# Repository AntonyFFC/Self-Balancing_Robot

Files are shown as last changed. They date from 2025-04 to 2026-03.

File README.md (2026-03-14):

# Self-Balancing Robot

A two-wheel self-balancing robot project combining embedded systems firmware, control theory, a cross-platform mobile app, and data-visualisation tools.

---

## Table of Contents

- [Overview](#overview)
- [Hardware](#hardware)
- [Repository Structure](#repository-structure)
- [Firmware Variants](#firmware-variants)
  - [ESP32 - Arduino IDE (primary)](#esp32---arduino-ide-primary)
  - [ESP32 - ESP-IDF](#esp32---esp-idf)
  - [STM32](#stm32)
  - [Arduino IDE (original)](#arduino-ide-original)
- [Control Algorithm](#control-algorithm)
- [Mobile App](#mobile-app)
- [Visualisation Tools](#visualisation-tools)
- [Simulations](#simulations)
- [CAD Models](#cad-models)
- [Getting Started](#getting-started)
- [License](#license)

---

## Overview

The robot maintains vertical balance on two wheels using a real-time PID control loop running at 100 Hz. An MPU6050 IMU provides pitch-angle feedback via its built-in DMP. The controller outputs PWM signals to an L298N dual H-bridge motor driver. The primary firmware runs on an **ESP32** microcontroller and uses built-in WiFi for real-time telemetry and remote PID tuning.

---

## Hardware

| Component | Details |
|---|---|
| **Microcontroller** | ESP32 dual-core (primary) · STM32F103 (alternative) |
| **IMU** | MPU6050 – 6-axis accelerometer & gyroscope (I²C, DMP firmware) |
| **Motor Driver** | L298N dual-channel H-bridge |
| **Wireless** | Built-in WiFi (ESP32) · nRF24L01+ 2.4 GHz RF module (STM32) |
| **Motors** | DC geared motors with PWM speed control |

### Chassis

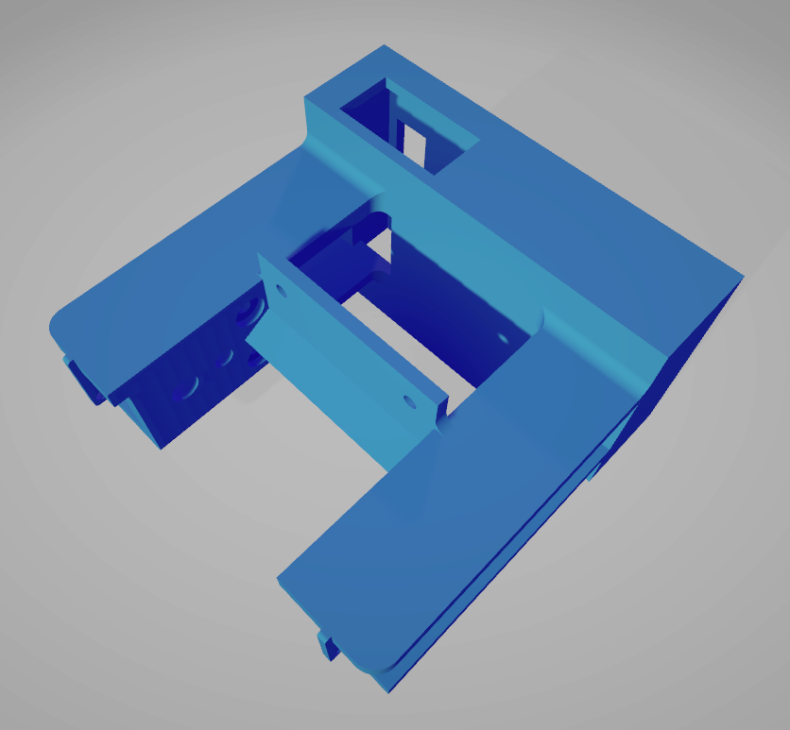
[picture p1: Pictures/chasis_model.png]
Chassis model


---

## Repository Structure

```
SelfBalancing-Robot/
├── esp32_s-b_r_fromArIDE/         # ESP32 firmware - Arduino IDE style (primary)
├── esp32_s-b_r/                   # ESP32 firmware - ESP-IDF / CMake
├── stm32_s-b_r/                   # STM32F1 firmware (CubeIDE)
├── stm32_s-b_r_t/                 # STM32F1 alternative / test build
├── self-balancing-robot_arduinoIDE/# Original Arduino IDE version
├── robot_control_app/             # Flutter cross-platform mobile app
├── Python_Plotting/               # Real-time UDP data visualisation
├── csv_py_plot/                   # CSV playback plotting
├── simulations/                   # MATLAB/Simulink models & analysis
├── CAD/                           # FreeCAD & STL 3D models
├── Pictures/                      # Project images
├── diagrams/                      # Architecture diagrams (Visual Paradigm)
└── Self-Balancing Robot.ssproj    # Serial Studio monitoring project
```

---

## Firmware Variants

### ESP32 - Arduino IDE (primary)

Located in `esp32_s-b_r_fromArIDE/`. This is the main firmware used in the project, built with the ESP-IDF toolchain (structured as an Arduino-IDE-friendly project).

**GPIO pin assignments:**

| Function | GPIO |
|---|---|
| I²C SDA (MPU6050) | 21 |
| I²C SCL (MPU6050) | 22 |
| MPU6050 DMP interrupt | 4 |
| Motor Left – Forward | 33 |
| Motor Left – Backward | 25 |
| Motor Right – Forward | 26 |
| Motor Right – Backward | 27 |

**Key features:**
- **Sensor:** MPU6050 with DMP firmware (42-byte FIFO packets, ~100 Hz pitch output)
- **Control loop:** `Balance_Control_task` at 10 ms (100 Hz), priority 10, pinned to core 1
- **Motor output:** LEDC PWM at 500 Hz, 14-bit resolution, with deadband compensation
- **WiFi:** Access-point mode (SSID `SBR_AP`, password `sbrpassword`)
- **Telemetry TX:** UDP port **7777** – `PITCH,SETPITCH,CONTROL_SIGNAL\n`
- **Command RX:** UDP port **7778** – live PID & movement commands
- **Startup safety:** waits for pitch to stabilise within ±3° of upright for 600 ms before enabling motors

**Build & flash:**
```bash
cd esp32_s-b_r_fromArIDE
idf.py set-target esp32
idf.py build
idf.py -p /dev/ttyUSB0 flash monitor
```

**Live PID tuning via UDP (port 7778):**
```
PID:Kp=9.0,1/Ti=0.0,Td=0.0,UPRIGHT=180.0,MIN_U=0.0
MOVE:FORWARD | BACKWARD | LEFT | RIGHT | STOP
```

---

### ESP32 - ESP-IDF

Located in `esp32_s-b_r/`. A more compact, monolithic implementation using the ESP-IDF CMake build system.

**Build:**
```bash
cd esp32_s-b_r
idf.py set-target esp32
idf.py build
idf.py flash monitor
```

---

### STM32

Located in `stm32_s-b_r/`. Built with STM32CubeIDE.

- **Control loop:** TIM3 interrupt at 100 Hz (10 ms period)
- **Sensor:** MPU6050 via I²C
- **Wireless:** nRF24L01+ via SPI – 4-byte payload (servo + motor ADC values)
- **Motor output:** PWM via TIM1 channels, with deadband compensation

**Build:** Open `stm32_s-b_r/` as an STM32CubeIDE project and build with the standard toolchain.

---

### Arduino IDE (original)

Located in `self-balancing-robot_arduinoIDE/`. Open the `.ino` sketch in the Arduino IDE and flash to a compatible board.

---

## Control Algorithm

### Pitch Estimation

The primary ESP32 firmware uses the **MPU6050 DMP** (Digital Motion Processor) to obtain pitch angle directly from the sensor's on-chip quaternion engine (~100 Hz, 42-byte FIFO packets). The pitch is expressed as 0–360°, where 180° represents the upright balanced position.

The STM32 variant uses a software **complementary filter**:
```
pitch = 0.95 × (pitch + gx × dt) + 0.05 × acc_pitch
```
- 95% weight on gyroscope integration (high-frequency accuracy)
- 5% weight on accelerometer angle (long-term drift correction)
- Accelerometer pitch: `atan2(ax, sqrt(ay² + az²))`

### Discrete PID Controller

```
K  = 2.5       (proportional gain)
Ti = 900 000   (integral time constant)
Td = 0.0       (derivative time constant – disabled)
Tp = 0.01 s    (sampling period, 10 ms)
```

Motor PWM output is clamped and a deadband of 22% is applied to overcome static friction.

---

## Mobile App

Located in `robot_control_app/`. Built with Flutter (SDK ≥ 3.7.2). Targets Android, iOS, Windows, Linux, macOS, and Web.

**Features:**
- Real-time pitch, set-pitch, and control-signal charts (custom `CustomPainter`)
- PID parameter sliders with live UDP updates to the robot
- Manual speed/direction control
- Data logging to CSV with export via `share_plus`

**Screenshots:**

| PID Tuning | Manual Control | Limits | Connection Status |
|---|---|---|---|
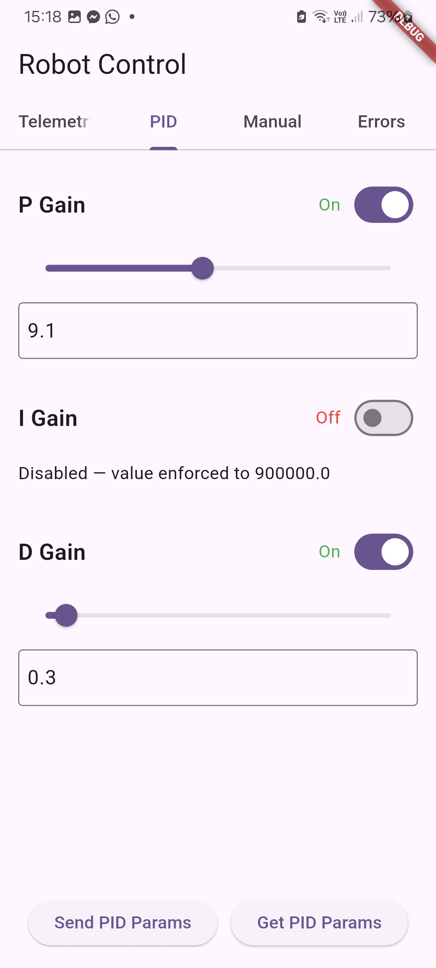
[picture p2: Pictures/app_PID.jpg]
PID
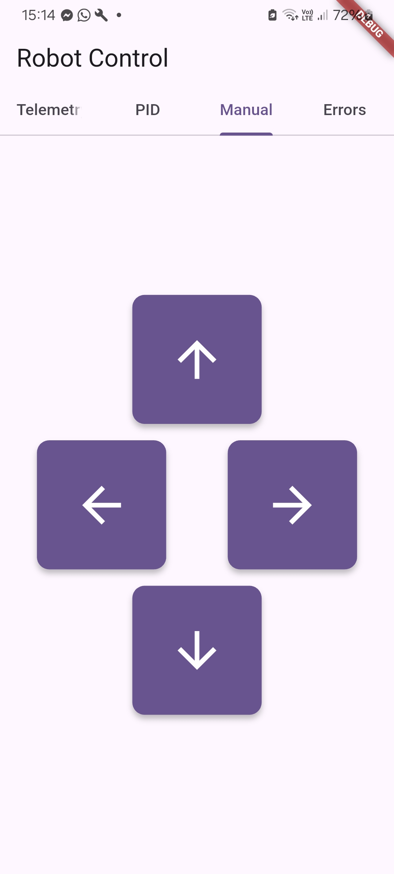
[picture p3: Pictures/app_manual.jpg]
Manual
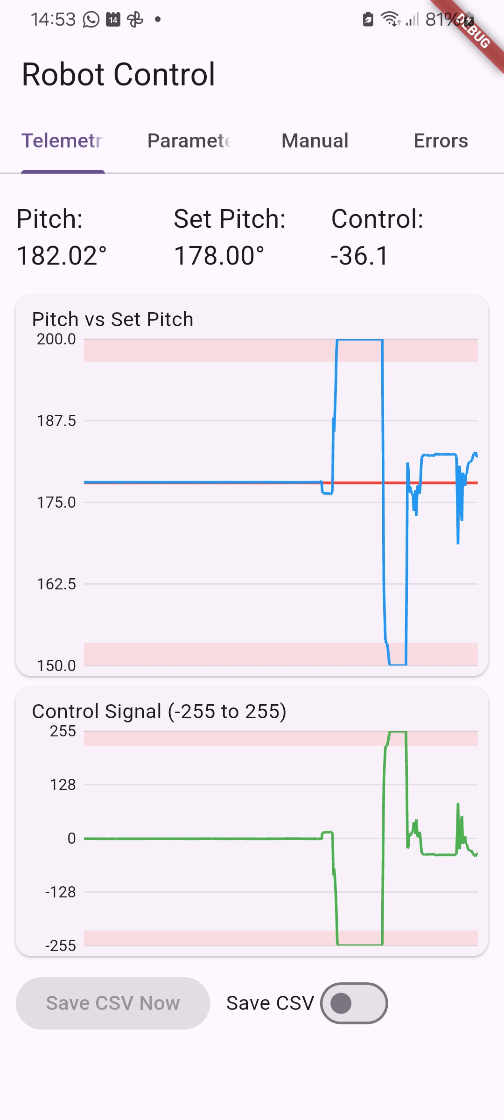
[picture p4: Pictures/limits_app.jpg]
Limits
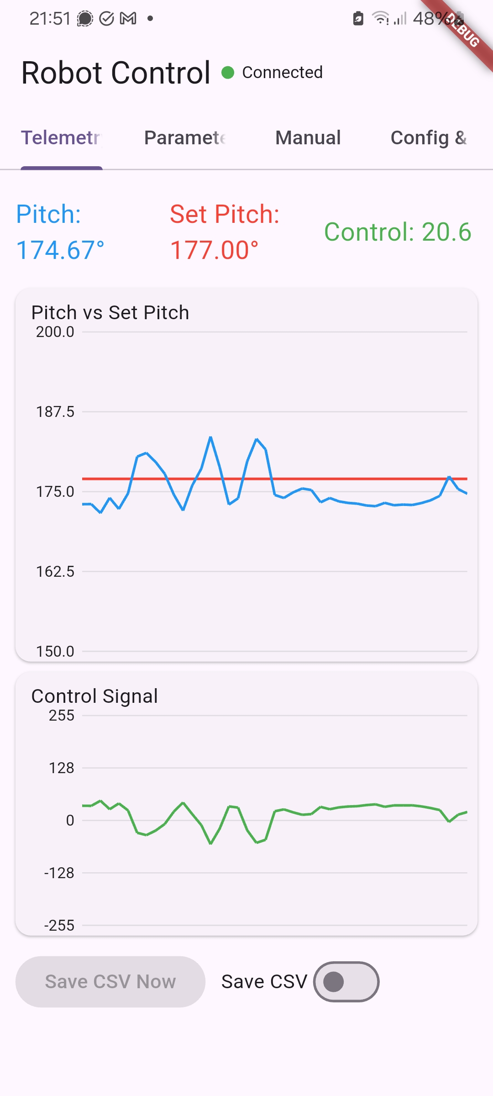
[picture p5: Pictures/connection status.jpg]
Connection
|  |  |  |  |

**Build & run:**
```bash
cd robot_control_app
flutter pub get
flutter run
```

---

## Visualisation Tools

### Python Real-Time Plotter

Located in `Python_Plotting/`. Receives UDP telemetry from the ESP32 and plots pitch, setpoint, and control signal in real time using `matplotlib`.

```bash
cd Python_Plotting
pip install matplotlib numpy
python dashboard.py
```

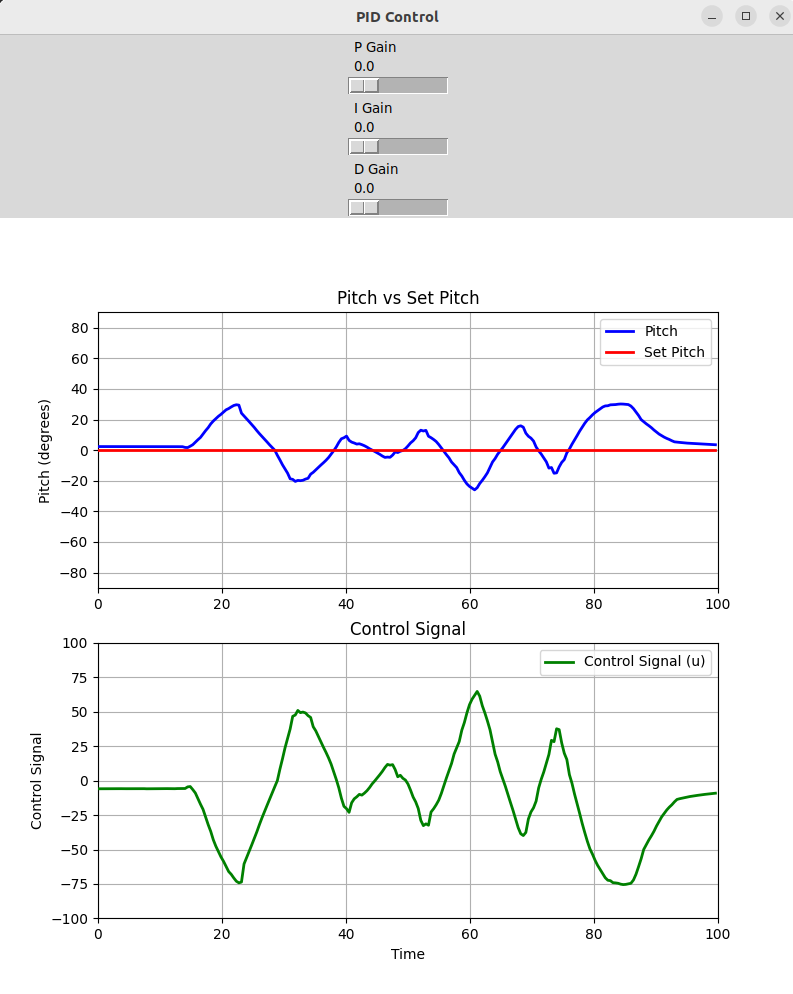
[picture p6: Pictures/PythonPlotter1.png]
Python Plotter

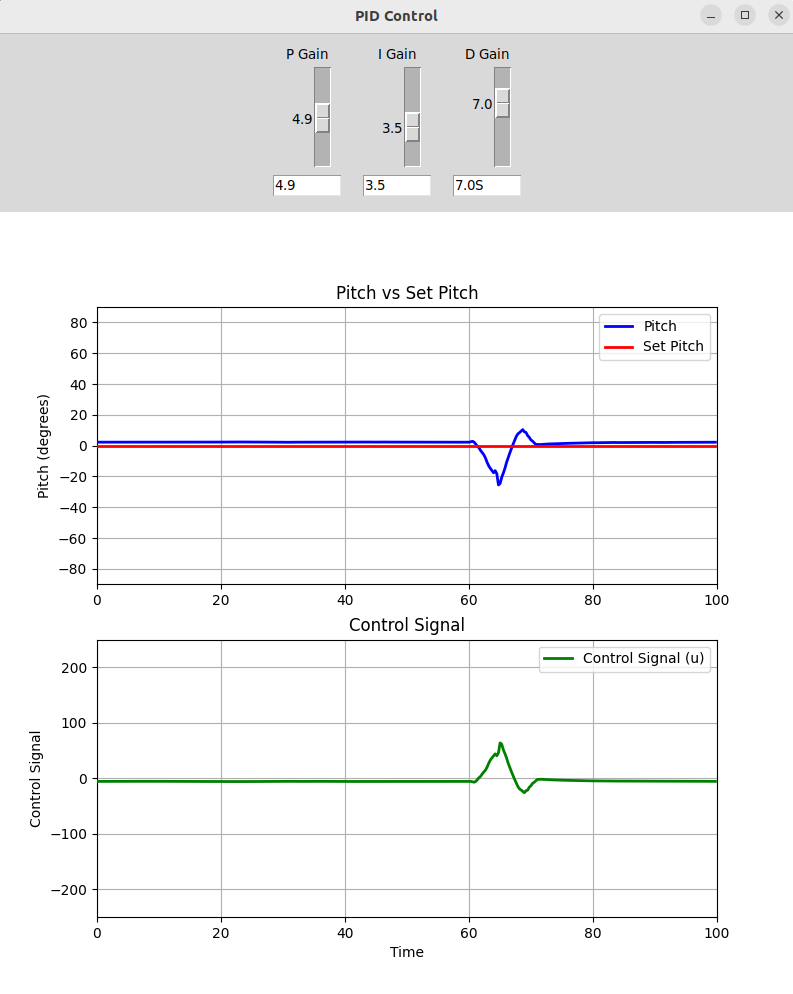
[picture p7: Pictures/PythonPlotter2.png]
Python Plotter plots


### Serial Studio

A pre-built Serial Studio project (`Self-Balancing Robot.ssproj`) parses the comma-separated telemetry stream and displays three datasets: Pitch, Set Pitch, and Control Signal.

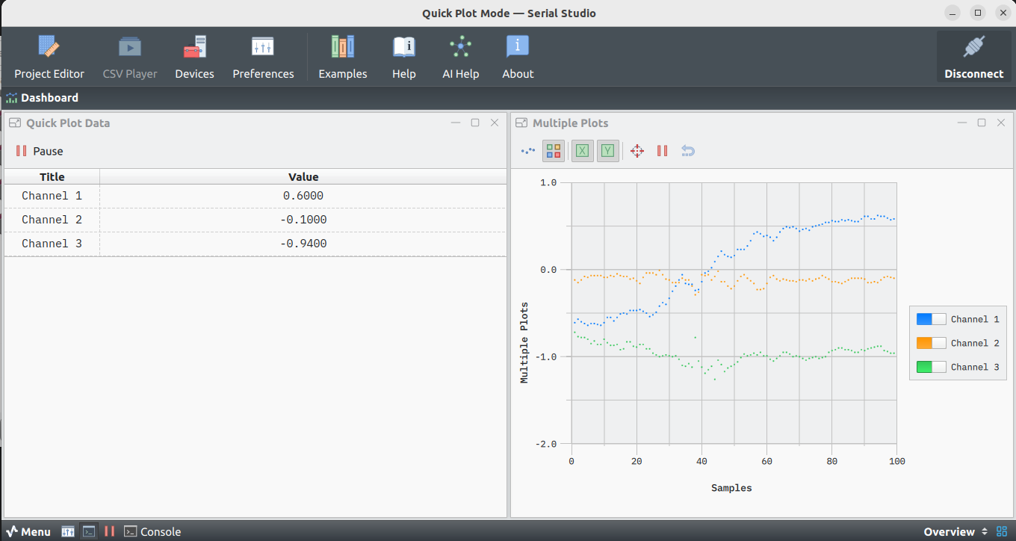
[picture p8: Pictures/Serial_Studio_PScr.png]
Serial Studio

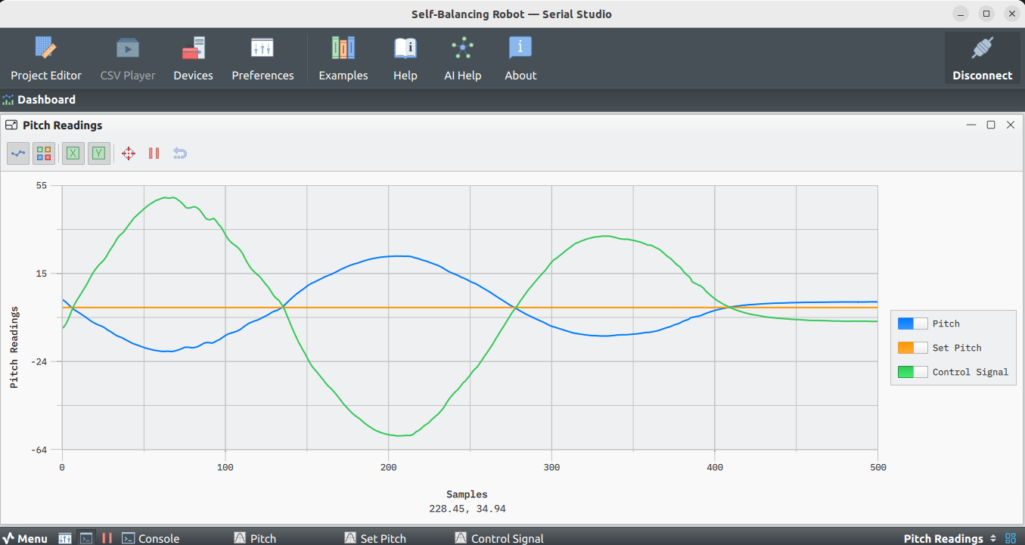
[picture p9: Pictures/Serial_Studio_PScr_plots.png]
Serial Studio plots


### CSV Plotter

Located in `csv_py_plot/`. Replays recorded CSV data for offline analysis.

---

## Simulations

Located in `simulations/`. Requires MATLAB with Simulink.

| File | Description |
|---|---|
| `model.slx` | Continuous-time Simulink model |
| `Dyskretny_PID.mlx` | Discrete PID controller design |
| `transmitancja.mlx` | Transfer function analysis |
| `zigler_nichols.mlx` | Ziegler–Nichols tuning method |
| `Simple_G/robot_imitation.m` | Simplified robot dynamics simulation |

---

## CAD Models

Located in `CAD/`. Designed in FreeCAD.

| File | Description |
|---|---|
| `Chassy1.FCStd` | Full parametric chassis model |
| `Chassy1.stl` | Exportable mesh for 3D printing |

---

## Getting Started

1. **Clone the repository**
   ```bash
   git clone https://github.com/AntonyFFC/SelfBalancing-Robot.git
   cd SelfBalancing-Robot
   ```

2. **Flash the primary firmware** (ESP32 – Arduino IDE variant):
   ```bash
   cd esp32_s-b_r_fromArIDE
   idf.py set-target esp32
   idf.py build
   idf.py -p /dev/ttyUSB0 flash monitor
   ```
   See [Firmware Variants](#firmware-variants) for alternative builds.

3. **Connect to the robot's WiFi access point** (`SBR_AP` / `sbrpassword`).

4. **Run the mobile app or Python plotter** to monitor and tune the robot wirelessly.

5. *(Optional)* Open the MATLAB simulations to analyse the control system or experiment with different PID parameters.

---

## License

This project is provided as-is for educational purposes. See the repository for any applicable licence information.

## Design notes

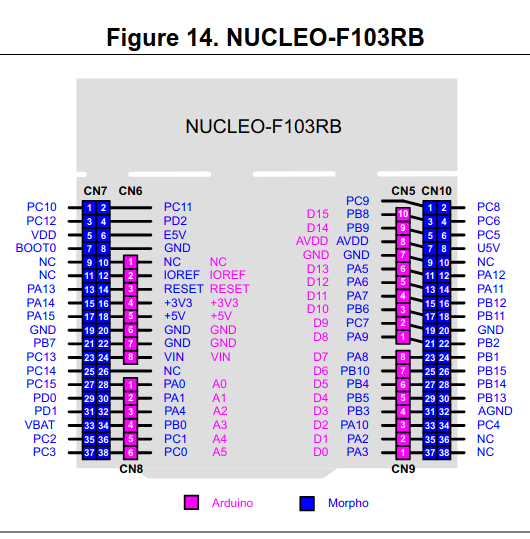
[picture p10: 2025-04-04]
Pictures/stm32nucleoF103RB_pinout.png

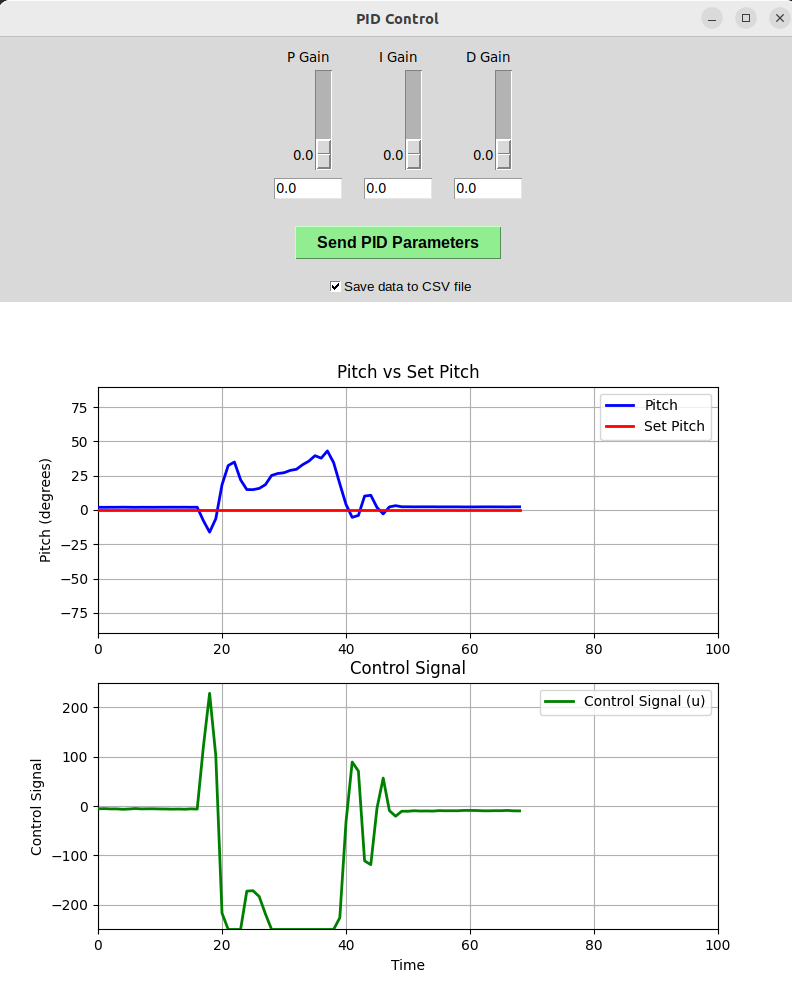
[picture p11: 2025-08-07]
Pictures/PythonPlotter3.png

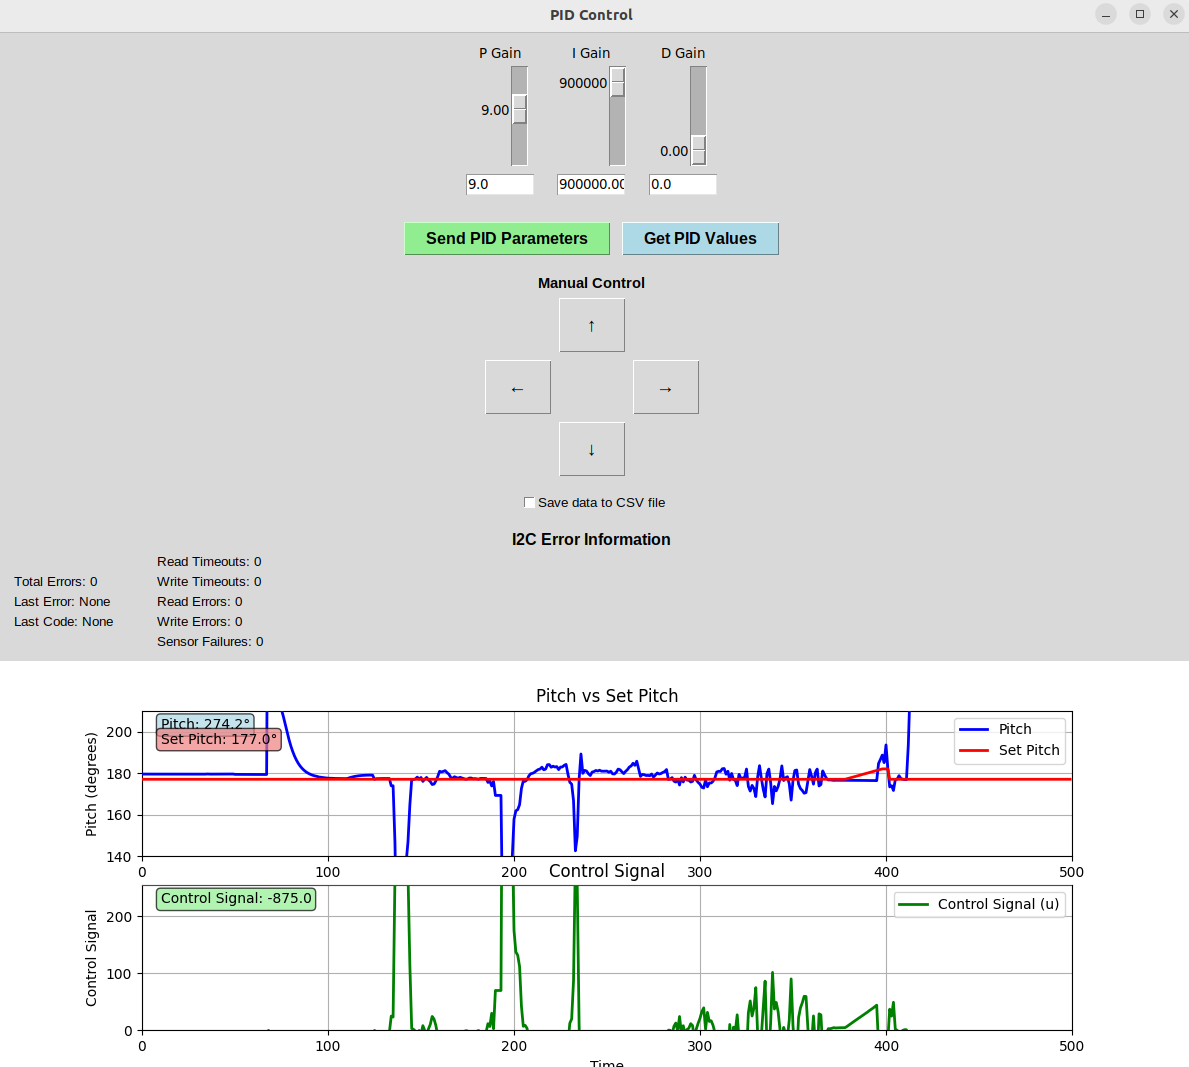
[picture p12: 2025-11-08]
Pictures/Screenshot from 2025-11-08 15-52-09.png

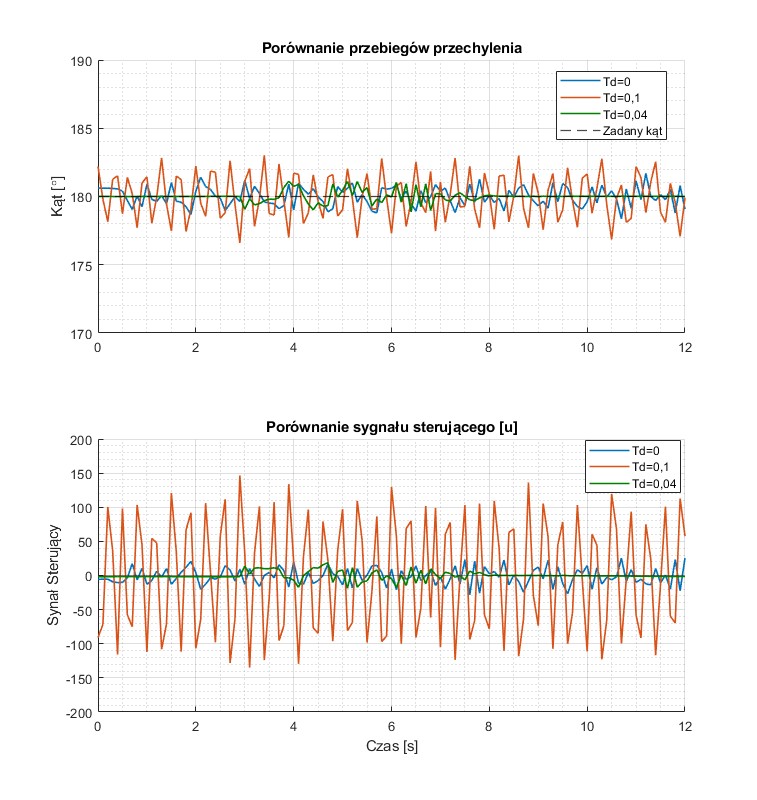
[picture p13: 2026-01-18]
simulations/porownanieTd.jpg

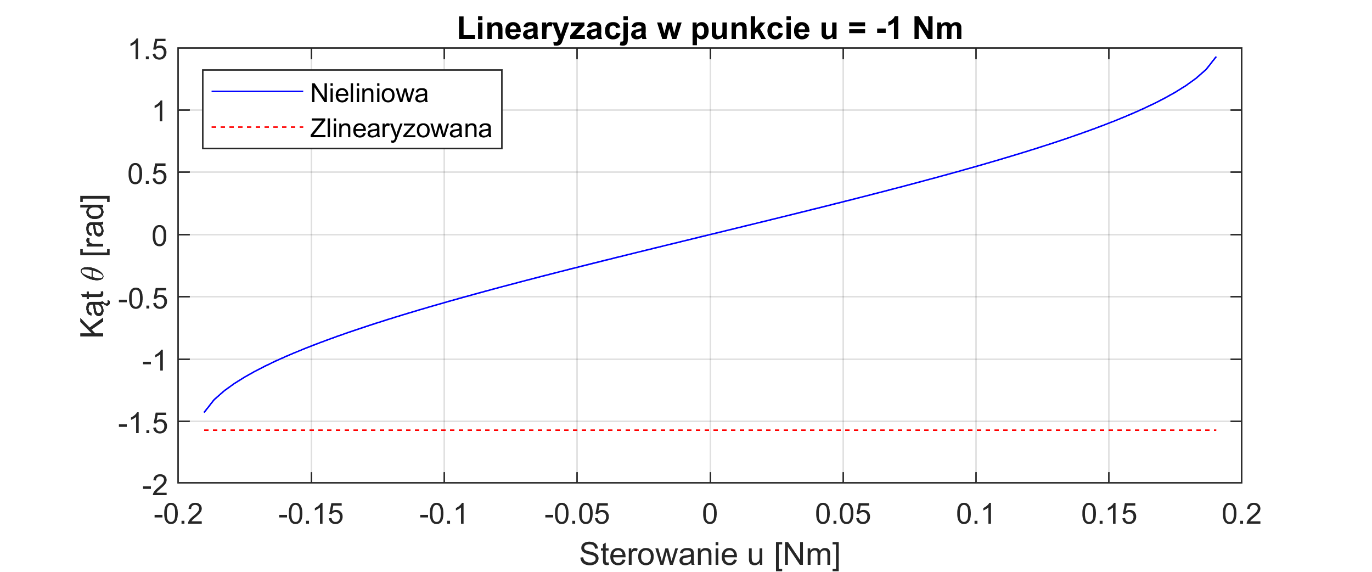
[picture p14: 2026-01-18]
simulations/charStatLin1.png

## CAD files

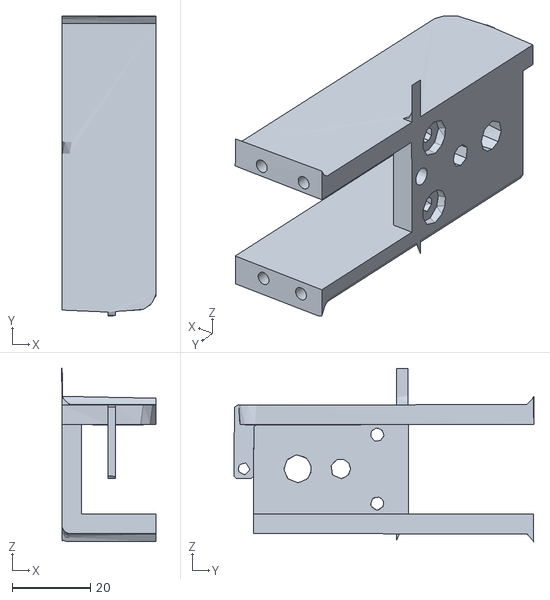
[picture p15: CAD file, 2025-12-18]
CAD/Chassy1cut_part_lleg.stl
24.0 x 76.4 x 44.1

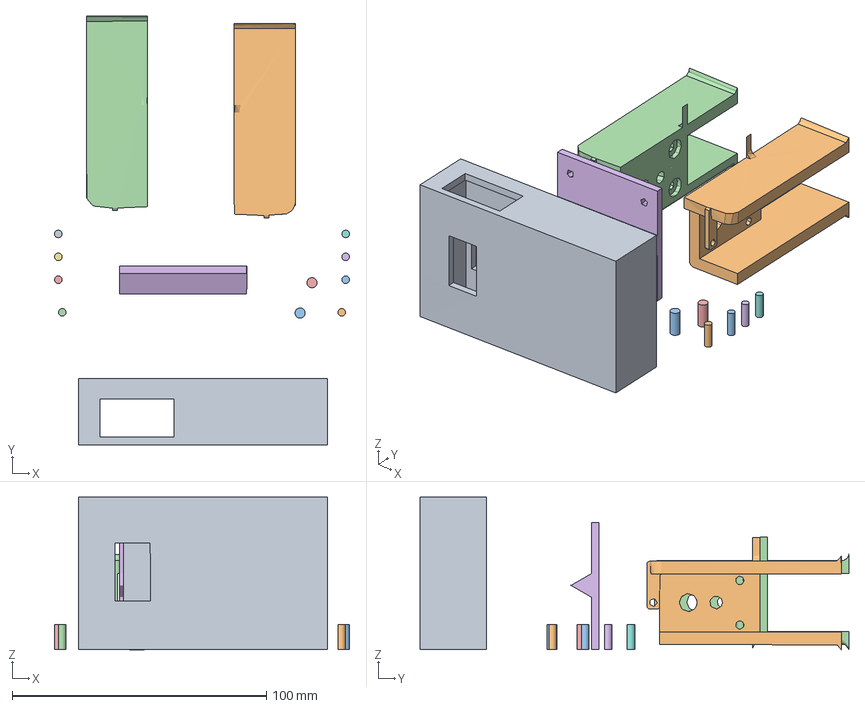
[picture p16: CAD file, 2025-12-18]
CAD/Chassy1.3mf
116.0 x 168.7 x 60.1 mm
Chassy1.stl x 4
Chassy1.stl-Dowel-Łącznik-1
Chassy1.stl-Dowel-Łącznik-2
Chassy1.stl-Dowel-Łącznik-3
Chassy1.stl-Dowel-Łącznik-4
Chassy1.stl-Dowel-Łącznik-5
Chassy1.stl-Dowel-Łącznik-6
Chassy1.stl-Dowel-Łącznik-7
Chassy1.stl-Dowel-Łącznik-8
Chassy1.stl-Dowel-Łącznik-9
Chassy1.stl-Dowel-Łącznik-10

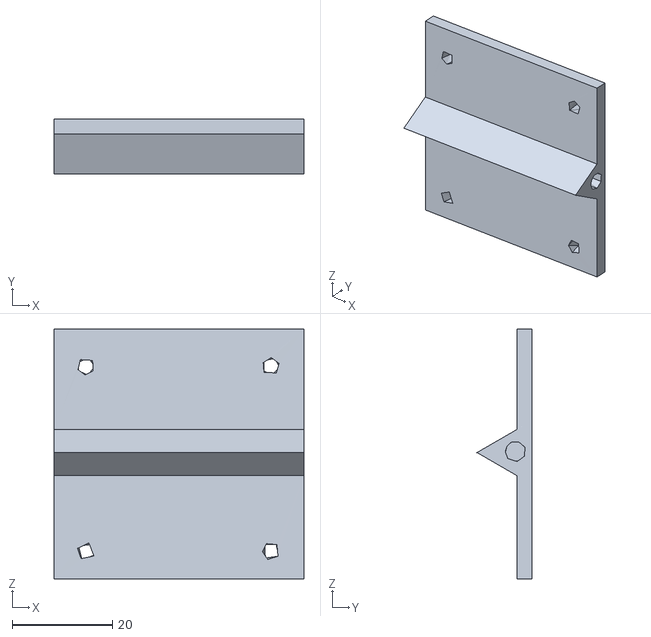
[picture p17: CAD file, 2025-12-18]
CAD/Chassy1cut_part_midle.stl
50.0 x 11.0 x 50.0

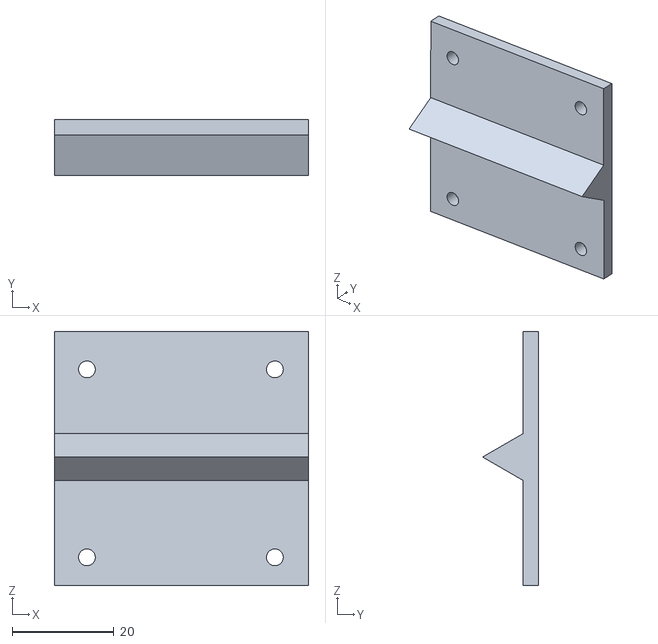
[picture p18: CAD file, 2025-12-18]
CAD/Chassy1_cut.stl
50.0 x 11.0 x 50.0

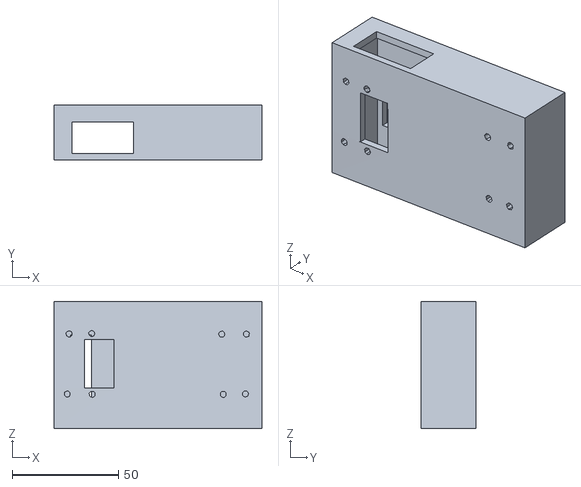
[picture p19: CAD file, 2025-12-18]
CAD/Chassy1cut_part_main.stl
98.0 x 26.1 x 60.0

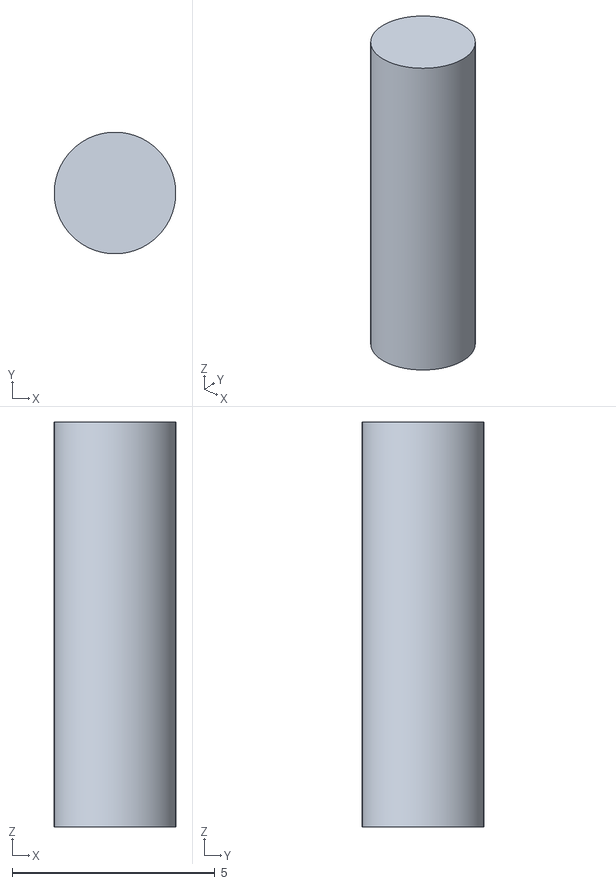
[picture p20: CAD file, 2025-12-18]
CAD/lacznik_x8.stl
3.00 x 3.00 x 10.0

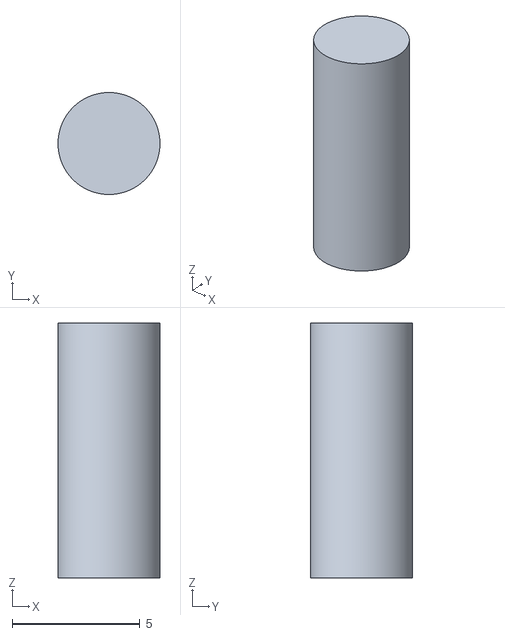
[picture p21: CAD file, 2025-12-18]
CAD/lacnik_x2.stl
4.00 x 4.00 x 10.0

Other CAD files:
CAD/Chassy1cut_part_rleg.stl
CAD/Chassy1.stl

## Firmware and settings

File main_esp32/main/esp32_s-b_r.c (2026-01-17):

#include <stdio.h>
#include <string.h>
#include <stdlib.h>
#include "esp_log.h"
#include "driver/i2c.h"
#include <math.h>
#include "freertos/FreeRTOS.h"
#include "freertos/task.h"
#include "freertos/queue.h"
#include "driver/ledc.h"
#include "driver/gpio.h"
#include "wifi.h"
#include "lwip/sockets.h"
#include "lwip/netdb.h"
#include "nvs_flash.h"
#include "cJSON.h"
#include "mpu6050.h"
#include "i2c_com.h"
#include "motor.h"

#define PYTHON_PLOTTER_DEBUG           CONFIG_PYTHON_PLOTTER_DEBUG

#ifndef M_PI
#define M_PI 3.14159265358979323846
#endif

#define DRIVE_ANGLE_OFFSET 5.0f
#define SPEED_SLEW_RATE 1.0f
#define TURN_OFFSET 70.0f
#define TURN_SLEW_RATE 10.0f

static volatile float drive_angle_offset = DRIVE_ANGLE_OFFSET;
static volatile float speed_slew_rate = SPEED_SLEW_RATE;
static volatile float turn_offset_val = TURN_OFFSET;
static volatile float turn_slew_rate = TURN_SLEW_RATE;

#define STARTUP_STABLE_THRESHOLD_DEG 3.0f
#define STARTUP_STABLE_COUNT 30
#define STARTUP_SAMPLE_INTERVAL_MS 20

static const char *TAG = "self-balancing-robot";

TaskHandle_t mpu_task_handle = NULL;

static float pid_K = 9.0f;
static float pid_1Ti = 0.0f;
static float pid_Td = 0.0f;
static float setPitch = 180.0f, u = 0.0f;
static float min_u = 0.0f; 
volatile float pitch = 0.0f;
static float upright_pitch = 180.0f;

static volatile bool motors_enabled = false;
static volatile bool request_pid_reset = false;

static volatile bool mpuInterrupt = false;
uint16_t packetSize;
bool dmpReady = false;

SemaphoreHandle_t pitch_mutex;
SemaphoreHandle_t u_mutex;
SemaphoreHandle_t move_mutex;
SemaphoreHandle_t setPitch_mutex;

typedef enum {
    MOVE_STOP = 0,
    MOVE_FORWARD,
    MOVE_BACKWARD,
    MOVE_LEFT,
    MOVE_RIGHT
} move_cmd_t;

static volatile move_cmd_t manual_move = MOVE_STOP;
// ============================================================================
// UDP DEBUG SECTION
// ============================================================================
#if PYTHON_PLOTTER_DEBUG

// #define DESTINATION_IP "192.168.1.161" //14 - pc //161 - phone
#define DESTINATION_PORT 7777
#define LISTEN_PORT 7778
#define UDP_MSG_MAX_LEN 128
#define UDP_SENDER_TASK_PERIOD_MS 100

int udp_sock;
struct sockaddr_in dest_addr;
static bool dest_addr_known = false;
int udp_listen_sock;
extern bool wifi_connected;

static uint32_t total_i2c_errors = 0;

static void udp_send_data(const char *data);

static void __attribute__((unused)) send_i2c_error(const char* error_type, esp_err_t error_code) {
    char error_msg[UDP_MSG_MAX_LEN];
    total_i2c_errors++;
    snprintf(error_msg, sizeof(error_msg), "I2C_ERROR:%s,code=0x%x,total=%lu\n", 
             error_type, error_code, total_i2c_errors);
    udp_send_data(error_msg);
}

esp_err_t my_udp_init(void) {
    if (!wifi_connected) {
        ESP_LOGE(TAG, "Wi-Fi not connected, delaying UDP init");
        return ESP_ERR_NOT_FOUND;
    }

    udp_sock = socket(AF_INET, SOCK_DGRAM, IPPROTO_IP);
    if (udp_sock < 0) {
        ESP_LOGE(TAG, "Unable to create socket: errno %d", errno);
        return ESP_FAIL;
    }

    // Adres docelowy zapisany po otrzymaniu komendy CONNECT
    dest_addr.sin_family = AF_INET;
    dest_addr.sin_port = htons(DESTINATION_PORT);
    dest_addr_known = false;

    ESP_LOGI(TAG, "UDP socket initialized successfully");
    return ESP_OK;
}

esp_err_t udp_server_init(void) {
    if (!wifi_connected) {
        ESP_LOGE(TAG, "Wi-Fi not connected, delaying UDP server init");
        return ESP_ERR_NOT_FOUND;
    }

    udp_listen_sock = socket(AF_INET, SOCK_DGRAM, IPPROTO_IP);
    if (udp_listen_sock < 0) {
        ESP_LOGE(TAG, "Unable to create listen socket: errno %d", errno);
        return ESP_FAIL;
    }

    struct sockaddr_in listen_addr;
    listen_addr.sin_family = AF_INET;
    listen_addr.sin_addr.s_addr = INADDR_ANY;
    listen_addr.sin_port = htons(LISTEN_PORT);

    int err = bind(udp_listen_sock, (struct sockaddr *)&listen_addr, sizeof(listen_addr));
    if (err < 0) {
        ESP_LOGE(TAG, "Socket unable to bind: errno %d", errno);
        close(udp_listen_sock);
        udp_listen_sock = -1;
        return ESP_FAIL;
    }

    ESP_LOGI(TAG, "UDP server socket initialized successfully on port %d", LISTEN_PORT);
    return ESP_OK;
}

static void udp_send_data(const char *data) {
    if (udp_sock < 0) {
        ESP_LOGE(TAG, "UDP socket not initialized");
        return;
    }
    if (!dest_addr_known) {
        ESP_LOGW(TAG, "UDP destination not known yet; not sending");
        return;
    }

    int err = sendto(udp_sock, data, strlen(data), 0, (struct sockaddr *)&dest_addr, sizeof(dest_addr));
    // if (err < 0) {
    //     ESP_LOGE(TAG, "Error occurred during sending: errno %d", errno);
    // } else {
    //     ESP_LOGI(TAG, "Data sent successfully: %s", data);
    // }
}

void send_initial_pid_values(void) {
    char init_msg[UDP_MSG_MAX_LEN];
    snprintf(init_msg, sizeof(init_msg), "INIT:Kp=%.3f,1/Ti=%.6f,Td=%.3f,UPRIGHT=%.3f,MIN_U=%.3f\n", 
             pid_K, pid_1Ti, pid_Td, upright_pitch, min_u);
    udp_send_data(init_msg);
    ESP_LOGI(TAG, "Sent initial PID values: %s", init_msg);
}

void parse_pid_command(const char* cmd) {
    float new_P = pid_K, new_I = pid_1Ti, new_D = pid_Td;
    float new_up = upright_pitch;
    float new_min_u = min_u;
    bool updated = false;

    if (strstr(cmd, "GET") != NULL) {
        send_initial_pid_values();
        return;
    }
    
    char* p_pos = strstr(cmd, "Kp=");
    if (p_pos != NULL) {
        new_P = atof(p_pos + 3);
        updated = true;
    }
    
    char* i_pos = strstr(cmd, "1/Ti=");
    if (i_pos != NULL) {
        float i_val = atof(i_pos + 5);
        new_I = i_val;
        updated = true;
    }
    
    char* d_pos = strstr(cmd, "Td=");
    if (d_pos != NULL) {
        new_D = atof(d_pos + 3);
        updated = true;
    }

    char* up_pos = strstr(cmd, "UPRIGHT=");
    if (up_pos != NULL) {
        char *sep = strchr(up_pos, '=');
        if (sep != NULL) {
            new_up = atof(sep + 1);
            updated = true;
        }
    }

    char* min_u_pos = strstr(cmd, "MIN_U=");
    if (min_u_pos != NULL) {
        char *sep = strchr(min_u_pos, '=');
        if (sep != NULL) {
            new_min_u = atof(sep + 1);
            updated = true;
        }
    }
    
    if (updated) {
        pid_K = new_P;
        pid_1Ti = new_I;
        pid_Td = new_D;
        if (new_up != upright_pitch) {
            upright_pitch = new_up;
            if (xSemaphoreTake(setPitch_mutex, pdMS_TO_TICKS(10)) == pdTRUE) {
                setPitch = upright_pitch;
                xSemaphoreGive(setPitch_mutex);
            } else {
                ESP_LOGW(TAG, "Could not obtain setPitch_mutex to update upright pitch");
            }
        }
        min_u = new_min_u;
        ESP_LOGI(TAG, "Updated - Kp=%.3f, 1/Ti=%.6f, Td=%.3f, Upright=%.3f, MIN_U=%.3f", 
                 pid_K, pid_1Ti, pid_Td, upright_pitch, min_u);
    }
}

void parse_move_command(const char* cmd) {
    const char *pos = strstr(cmd, "MOVE:");
    if (!pos) return;

    pos += strlen("MOVE:");
    char token[32];
    int i = 0;
    while (*pos && i < (int)sizeof(token)-1) {
        if (*pos == '\r' || *pos == '\n') break;
        token[i++] = *pos++;
    }
    token[i] = '\0';

    move_cmd_t new_cmd = MOVE_STOP;
    if (strcasecmp(token, "FORWARD") == 0) new_cmd = MOVE_FORWARD;
    else if (strcasecmp(token, "BACKWARD") == 0) new_cmd = MOVE_BACKWARD;
    else if (strcasecmp(token, "LEFT") == 0) new_cmd = MOVE_LEFT;
    else if (strcasecmp(token, "RIGHT") == 0) new_cmd = MOVE_RIGHT;
    else if (strcasecmp(token, "STOP") == 0) new_cmd = MOVE_STOP;
    else {
        ESP_LOGW(TAG, "Unknown MOVE token: %s", token);
        return;
    }

    if (xSemaphoreTake(move_mutex, pdMS_TO_TICKS(10)) == pdTRUE) {
        manual_move = new_cmd;
        xSemaphoreGive(move_mutex);
        ESP_LOGI(TAG, "Manual move set to %s", token);
    } else {
        ESP_LOGW(TAG, "Could not obtain move_mutex to set manual move");
    }
}

void parse_manual_settings(const char* cmd) {
    const char *pos = strstr(cmd, "MAN_SET:");
    if (!pos) return;

    char *dao_pos = strstr(cmd, "DAO=");
    char *ssr_pos = strstr(cmd, "SSR=");
    char *to_pos = strstr(cmd, "TO=");
    char *tsr_pos = strstr(cmd, "TSR=");

    bool updated = false;
    if (dao_pos) {
        float v = atof(dao_pos + 4);
        drive_angle_offset = v;
        updated = true;
    }
    if (ssr_pos) {
        float v = atof(ssr_pos + 4);
        speed_slew_rate = v;
        updated = true;
    }
    if (to_pos) {
        float v = atof(to_pos + 3);
        turn_offset_val = v;
        updated = true;
    }
    if (tsr_pos) {
        float v = atof(tsr_pos + 4);
        turn_slew_rate = v;
        updated = true;
    }

    if (updated) {
        ESP_LOGI(TAG, "Updated manual settings: DAO=%.3f, SSR=%.3f, TO=%.3f, TSR=%.3f",
                 drive_angle_offset, speed_slew_rate, turn_offset_val, turn_slew_rate);
    }
}

void init_debug_features(void) {
    ESP_ERROR_CHECK(my_udp_init());
    ESP_ERROR_CHECK(udp_server_init());
    ESP_LOGI(TAG, "UDP debug features enabled");
}

#endif // PYTHON_PLOTTER_DEBUG
// ============================================================================

#define MPU_INT 4
#define TASK_PERIOD_MS 10 //10

void update_ramped_speed(float *current_speed, float target_speed, float slew_rate, float dt)
{
    if (*current_speed < target_speed) {
        *current_speed += slew_rate * dt;
        if (*current_speed > target_speed) {
            *current_speed = target_speed;
        }
    } else if (*current_speed > target_speed) {
        *current_speed -= slew_rate * dt;
        if (*current_speed < target_speed) {
            *current_speed = target_speed;
        }
    }
}

void update_ramped_turn(float *current_turn, float target_turn, float slew_rate, float dt)
{
    if (*current_turn < target_turn) {
        *current_turn += slew_rate * dt;
        if (*current_turn > target_turn) {
            *current_turn = target_turn;
        }
    } else if (*current_turn > target_turn) {
        *current_turn -= slew_rate * dt;
        if (*current_turn < target_turn) {
            *current_turn = target_turn;
        }
    }
}

static void wait_for_stable_pitch_and_enable(void)
{
    ESP_LOGI(TAG, "Waiting for stable pitch around %.2f deg...", upright_pitch);
    int consecutive = 0;
    while (consecutive < STARTUP_STABLE_COUNT) {
        float sample = 0.0f;
        if (xSemaphoreTake(pitch_mutex, pdMS_TO_TICKS(20)) == pdTRUE) {
            sample = pitch;
            xSemaphoreGive(pitch_mutex);
        } else {
            vTaskDelay(pdMS_TO_TICKS(STARTUP_SAMPLE_INTERVAL_MS));
            continue;
        }

        float diff = fabsf(sample - upright_pitch);
        if (diff <= STARTUP_STABLE_THRESHOLD_DEG) {
            consecutive++;
        } else {
            if (consecutive > 0) {
                ESP_LOGI(TAG, "Stability broken (diff %.2f), resetting counter", diff);
            }
            consecutive = 0;
        }
        vTaskDelay(pdMS_TO_TICKS(STARTUP_SAMPLE_INTERVAL_MS));
    }

    motors_enabled = true;
    request_pid_reset = true;
    ESP_LOGI(TAG, "Pitch stable — motors enabled");
}

void IRAM_ATTR mpu_isr_handler(void* arg)
{
    BaseType_t xHigherPriorityTaskWoken = pdFALSE;
    vTaskNotifyGiveFromISR(mpu_task_handle, &xHigherPriorityTaskWoken);
    portYIELD_FROM_ISR(xHigherPriorityTaskWoken);
}

float PID(float y, float yzad)
{
	const float Tp = TASK_PERIOD_MS / 1000.0f; //czas próbkowania
	const float K = pid_K;
	const float _1Ti = pid_1Ti;
	const float Td = pid_Td;
    const float max_u = 255.0f;

	static float this_u =  0.0f;

	//bledy:
	static float e = 0.0f, e_1 = 0.0f, e_2 = 0.0f;

    static float last_K = 0.0f, last_1Ti = 0.0f, last_Td = 0.0f;
    static float r2, r1, r0;
    
    if (K != last_K || _1Ti != last_1Ti || Td != last_Td || request_pid_reset) {
        request_pid_reset = false;
        this_u = 0.0f;
        e = 0.0f;
        e_1 = 0.0f;
        e_2 = 0.0f;
        last_K = K;
        last_1Ti = _1Ti;
        last_Td = Td;
        r2 = (K*Td)/Tp;
        r1 = K*(((Tp/2)*_1Ti)-(2*Td/Tp)-1);
        r0 = K*(1+((Tp/2)*_1Ti)+(Td/Tp));
        ESP_LOGI(TAG, "PID controller reset due to parameter change");
    }

	//aktualizacja bledow:
	e_2 = e_1;
	e_1 = e;
	e = yzad - y;

	// float prev_u = this_u;
	this_u = r2*e_2 + r1*e_1 + r0*e + this_u;
	
	if (this_u > max_u) this_u = max_u;
	if (this_u < -max_u) this_u = -max_u;

    // float delta_u = this_u - prev_u;
	
	// ESP_LOGI(TAG, "PID: y=%.2f yzad=%.2f e=%.2f e_1=%.2f e_2=%.2f", y, yzad, e, e_1, e_2);
	// ESP_LOGI(TAG, "PID: r0=%.3f r1=%.3f r2=%.3f prev_u=%.2f delta=%.2f this_u=%.2f", 
	//          r0, r1, r2, prev_u, delta_u, this_u);
	
	return this_u;
}

void Data_Acquisition_task(void *arg)
{
    for(;;)
    {
        ulTaskNotifyTake(pdTRUE, portMAX_DELAY);

        uint8_t mpuIntStatus;
        uint16_t fifoCount;
        uint8_t fifoBuffer[64];
        float newPitch;
        static Quaternion q;
        static VectorFloat gravity;
        static float ypr[3];

        mpu6050_get_int_status(&mpuIntStatus);
        mpu6050_get_fifo_count(&fifoCount);

        if (mpu6050_check_fifo_oflow(mpuIntStatus, fifoCount)) {
            ESP_LOGW(TAG, "FIFO overflow detected, resetting FIFO");
            mpu6050_reset_fifo();
            continue;
        }

        if (mpu6050_check_dmp_status(mpuIntStatus)) {
            while (fifoCount < packetSize) {
                mpu6050_get_fifo_count(&fifoCount);
            }

            mpu6050_get_fifo_bytes(fifoBuffer, packetSize);
            mpu6050_parse_fifo_packet(fifoBuffer, &q, &gravity, ypr);

            newPitch = ypr[1] * 180 / M_PI;
            if (newPitch < 0) newPitch += 360;
            // ESP_LOGW(TAG, "Pitch: %.2f", newPitch);

            if (xSemaphoreTake(pitch_mutex, pdMS_TO_TICKS(5)) == pdTRUE) {
                pitch = newPitch;
                xSemaphoreGive(pitch_mutex);
            }
        }
    }
}


void Balance_Control_task(void *arg)
{
    TickType_t last_wake_time = xTaskGetTickCount();
    const float max_u = 255.0f;//200.0f
    
    while (true)
    {
        vTaskDelayUntil(&last_wake_time, pdMS_TO_TICKS(TASK_PERIOD_MS));

        if (!dmpReady) continue;
 
        float local_pitch;
        if (xSemaphoreTake(pitch_mutex, pdMS_TO_TICKS(5)) == pdTRUE) {
            local_pitch = pitch;
            xSemaphoreGive(pitch_mutex);
        } else {
            continue;
        }

        float local_setPitch;
        if (xSemaphoreTake(setPitch_mutex, pdMS_TO_TICKS(5)) == pdTRUE) {
            local_setPitch = setPitch;
            xSemaphoreGive(setPitch_mutex);
        } else {
            continue;
        }

        float local_min_u = min_u; 

        move_cmd_t local_move;
        if (xSemaphoreTake(move_mutex, pdMS_TO_TICKS(5)) == pdTRUE) {
            local_move = manual_move;
            xSemaphoreGive(move_mutex);
        } else {
            continue;
        }

        static float turnOffset = 0.0f;

        if (local_move == MOVE_STOP)
        {
            update_ramped_speed(&local_setPitch, upright_pitch, speed_slew_rate, TASK_PERIOD_MS / 1000.0f);
            update_ramped_turn(&turnOffset, 0.0f, turn_slew_rate, TASK_PERIOD_MS / 1000.0f);
        } else if (local_move == MOVE_FORWARD) {
            update_ramped_speed(&local_setPitch, upright_pitch - drive_angle_offset, speed_slew_rate, TASK_PERIOD_MS / 1000.0f);
        } else if (local_move == MOVE_BACKWARD) {
            update_ramped_speed(&local_setPitch, upright_pitch + drive_angle_offset, speed_slew_rate, TASK_PERIOD_MS / 1000.0f);
        } else if (local_move == MOVE_LEFT) {
            update_ramped_turn(&turnOffset, -turn_offset_val, turn_slew_rate, TASK_PERIOD_MS / 1000.0f);
            update_ramped_speed(&local_setPitch, upright_pitch, speed_slew_rate, TASK_PERIOD_MS / 1000.0f);
        } else if (local_move == MOVE_RIGHT) {
            update_ramped_turn(&turnOffset, turn_offset_val, turn_slew_rate, TASK_PERIOD_MS / 1000.0f);
            update_ramped_speed(&local_setPitch, upright_pitch, speed_slew_rate, TASK_PERIOD_MS / 1000.0f);
        }
        
        float local_u = PID(local_pitch, local_setPitch);

        float left_u = local_u + turnOffset;
        float right_u = local_u - turnOffset;

        if (left_u > 0.001f) {
            left_u += local_min_u;
        } else if (left_u < -0.001f) {
            left_u -= local_min_u;
        }

        if (right_u > 0.001f) {
            right_u += local_min_u;
        } else if (right_u < -0.001f) {
            right_u -= local_min_u;
        }

        if (left_u > max_u) left_u = max_u;
        if (left_u < -max_u) left_u = -max_u;
        if (right_u > max_u) right_u = max_u;
        if (right_u < -max_u) right_u = -max_u;

        float left_abs_control = fabs(left_u);
        float right_abs_control = fabs(right_u);
        float left_pwm_ratio = (left_abs_control / max_u);
        float right_pwm_ratio = (right_abs_control / max_u);
        
        if (motors_enabled && local_pitch>150.0f && local_pitch < 200 && local_u < (2*max_u) && local_u > -(2*max_u)) {
        // if (motors_enabled && local_pitch>150.0f && local_pitch < 200) {
            if(left_u<0)
            {
                motor_left_forward(left_pwm_ratio);
            }
            else if (left_u>0)
            {
                motor_left_backward(left_pwm_ratio);
            }

            if(right_u<0)
            {
                motor_right_forward(right_pwm_ratio);
            }
            else if (right_u>0)
            {
                motor_right_backward(right_pwm_ratio);
            }
        } else {
            motor_stop();
        }

        if (xSemaphoreTake(u_mutex, pdMS_TO_TICKS(5)) == pdTRUE) {
            u = local_u;
            xSemaphoreGive(u_mutex);
        } else {
            continue;
        }

        if (xSemaphoreTake(setPitch_mutex, pdMS_TO_TICKS(5)) == pdTRUE) {
            setPitch = local_setPitch;
            xSemaphoreGive(setPitch_mutex);
        } else {
            continue;
        }
    }
}

#if PYTHON_PLOTTER_DEBUG

void udp_sender_task(void *arg)
{
    char msg[UDP_MSG_MAX_LEN/2];
    TickType_t last_wake_time = xTaskGetTickCount();

    while (true) {
        float latest_pitch, latest_setPitch, latest_u;

        if (xSemaphoreTake(pitch_mutex, pdMS_TO_TICKS(5)) == pdTRUE)
        {
            latest_pitch = pitch;
            xSemaphoreGive(pitch_mutex);
        } else {
            continue;
        }

        if (xSemaphoreTake(setPitch_mutex, pdMS_TO_TICKS(5)) == pdTRUE) {
            latest_setPitch = setPitch;
            xSemaphoreGive(setPitch_mutex);
        } else {
            continue;
        }

        if (xSemaphoreTake(u_mutex, pdMS_TO_TICKS(5)) == pdTRUE)
        {
            latest_u = u;
            xSemaphoreGive(u_mutex);
        } else {
            continue;
        }

        snprintf(msg, sizeof(msg), "%.2f,%.2f,%.2f\n", latest_pitch, latest_setPitch, latest_u);
        udp_send_data(msg);
        vTaskDelayUntil(&last_wake_time, pdMS_TO_TICKS(UDP_SENDER_TASK_PERIOD_MS));
    }
}

void udp_receiver_task(void *arg)
{
    char rx_buffer[UDP_MSG_MAX_LEN/2];
    struct sockaddr_in source_addr;
    socklen_t socklen = sizeof(source_addr);
    
    while (true) {
        if (udp_listen_sock < 0) {
            ESP_LOGE(TAG, "UDP listen socket not initialized, retrying...");
            vTaskDelay(pdMS_TO_TICKS(5000));
            continue;
        }
        
        int len = recvfrom(udp_listen_sock, rx_buffer, sizeof(rx_buffer) - 1, 0, 
                        (struct sockaddr *)&source_addr, &socklen);
        
        if (len < 0) {
            ESP_LOGE(TAG, "recvfrom failed: errno %d", errno);
            vTaskDelay(pdMS_TO_TICKS(1000));
            continue;
        }
        
    rx_buffer[len] = 0;

    char addr_str[128];
    inet_ntoa_r(((struct sockaddr_in *)&source_addr)->sin_addr.s_addr, addr_str, sizeof(addr_str) - 1);
    ESP_LOGI(TAG, "Received %d bytes from %s: %s", len, addr_str, rx_buffer);


        if (strstr(rx_buffer, "CONNECT") != NULL) {
            dest_addr = source_addr;
            dest_addr.sin_port = htons(DESTINATION_PORT);
            dest_addr_known = true;
            ESP_LOGI(TAG, "CONNECT received — remote set to %s, sending INIT", addr_str);
            send_initial_pid_values();
        } else if (!dest_addr_known) {
            ESP_LOGI(TAG, "Ignoring packet before CONNECT from %s", addr_str);
        } else if (strstr(rx_buffer, "MOVE:") != NULL) {
            parse_move_command(rx_buffer);
        } else if (strstr(rx_buffer, "MAN_SET:") != NULL) {
            parse_manual_settings(rx_buffer);
        } else {
            parse_pid_command(rx_buffer);
        }
    }
}

#endif // PYTHON_PLOTTER_DEBUG
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
// void app_main(void)
// {
//     ESP_ERROR_CHECK(i2c_master_init());
//     mpu6050_init();
    
//     uint8_t dev_id;
//     if (mpu6050_get_who_am_i(&dev_id) != ESP_OK) {
//         ESP_LOGE(TAG, "MPU6050 not found!");
//         return;
//     }
//     ESP_LOGI(TAG, "MPU6050 found. ID: %x", dev_id);

//     mpu6050_set_z_accel_offset(0);
//     mpu6050_set_x_gyro_offset(0);
//     mpu6050_set_y_gyro_offset(0);
//     mpu6050_set_z_gyro_offset(0);

//     vTaskDelay(pdMS_TO_TICKS(2000));

//     ESP_LOGI(TAG, "Reading initial values...");
//     meansensors();

//     ESP_LOGI(TAG, "Calibrating...");
//     calibration();

//     ESP_LOGI(TAG, "Verifying...");
//     meansensors();

//     printf("FINAL OFFSETS:\n");
//     printf("x gyro offset: %d\n", gx_offset);
//     printf("y gyro offset: %d\n", gy_offset);
//     printf("z gyro offset: %d\n", gz_offset);
//     printf("z accel offset: %d\n", az_offset);
    
//     while(1) { vTaskDelay(1000); }
// }

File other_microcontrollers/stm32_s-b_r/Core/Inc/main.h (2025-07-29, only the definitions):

#define B1_Pin GPIO_PIN_13
#define B1_GPIO_Port GPIOC
#define B1_EXTI_IRQn EXTI15_10_IRQn
#define CE_Pin GPIO_PIN_2
#define CE_GPIO_Port GPIOA
#define USART_RX_Pin GPIO_PIN_3
#define USART_RX_GPIO_Port GPIOA
#define CSN_Pin GPIO_PIN_7
#define CSN_GPIO_Port GPIOC
#define IN2_Pin GPIO_PIN_8
#define IN2_GPIO_Port GPIOA
#define IRQ_Pin GPIO_PIN_9
#define IRQ_GPIO_Port GPIOA
#define IRQ_EXTI_IRQn EXTI9_5_IRQn
#define IN1_Pin GPIO_PIN_10
#define IN1_GPIO_Port GPIOA
#define TMS_Pin GPIO_PIN_13
#define TMS_GPIO_Port GPIOA
#define TCK_Pin GPIO_PIN_14
#define TCK_GPIO_Port GPIOA
#define IN3_Pin GPIO_PIN_4
#define IN3_GPIO_Port GPIOB
#define IN4_Pin GPIO_PIN_5
#define IN4_GPIO_Port GPIOB

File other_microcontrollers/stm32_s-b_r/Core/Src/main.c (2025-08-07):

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
/* Includes ------------------------------------------------------------------*/
#include "main.h"
#include "i2c.h"
#include "spi.h"
#include "tim.h"
#include "gpio.h"

/* USER CODE BEGIN Includes */
#include <math.h>
#include <stdio.h>
#include "nrf24l01p.h"
/* USER CODE END Includes */

/* USER CODE BEGIN PM */
#define ACC_I2C_ADDR 0b1101000 << 1
#define ACCEL_START_REG 0x3B
#define GYRO_START_REG 0x43
#define WHO_AM_I_REG 0x75
/* USER CODE END PM */


/* USER CODE BEGIN PV */
uint8_t rx_data[NRF24L01P_PAYLOAD_LENGTH] = { 0 };
uint16_t adc_value_servo;
uint16_t adc_value_motor;
float gyroXoffset, gyroYoffset, gyroZoffset;
/* USER CODE END PV */

void SystemClock_Config(void);
/* USER CODE BEGIN PFP */
extern void initialise_monitor_handles(void);
/* USER CODE END PFP */

/* USER CODE BEGIN 0 */
void HAL_GPIO_EXTI_Callback(uint16_t GPIO_Pin);

void read3dData(I2C_HandleTypeDef* hi2c, float* x, float* y, float* z, float rangeFactor, uint8_t startReg)
{
	  int16_t rawX,rawY,rawZ;
	  uint8_t i2c_receive8bit_buf[6];
	  const uint8_t bytes_to_receive = 6;

	  HAL_I2C_Mem_Read(hi2c, ACC_I2C_ADDR, startReg,1, i2c_receive8bit_buf, bytes_to_receive, 10);
	  rawX = (int16_t)(i2c_receive8bit_buf[0]<<8 | i2c_receive8bit_buf[1]);
	  rawY = (int16_t)(i2c_receive8bit_buf[2]<<8 | i2c_receive8bit_buf[3]);
	  rawZ = (int16_t)(i2c_receive8bit_buf[4]<<8 | i2c_receive8bit_buf[5]);

	  *x = (float)rawX/pow(2,15)*rangeFactor;
	  *y = (float)rawY/pow(2,15)*rangeFactor;
	  *z = (float)rawZ/pow(2,15)*rangeFactor;
}

void readAccelerometer(I2C_HandleTypeDef* hi2c, float* x, float* y, float* z)
{
	  const float wspolczynnik = 2;
	  read3dData(hi2c, x, y, z, wspolczynnik, ACCEL_START_REG);
}

void readGyroscope(I2C_HandleTypeDef* hi2c, float* x, float* y, float* z)
{
	const float wspolczynnik = 250.0f;
	read3dData(hi2c, x, y, z, wspolczynnik, GYRO_START_REG);
}

void calculatePitch(float *pitch, float ax, float ay, float az, float gx, float dt)
{
	const float alpha = 0.95;
	float acc_pitch = atan2(ax, sqrt(ay*ay+az*az)) * 180.0 / M_PI;
	// float acc_pitch = atan2(az, sqrt(ax*ax + ay*ay)) * (180.0 / M_PI); // Alternative vertical formula
	*pitch = alpha * (*pitch + gx * dt) + (1.0f-alpha) * acc_pitch;
}

float PID(float y, float yzad)
{
	const float Tp = 0.01f; //czas próbkowania
	const float K =  2.5f;
	const float Ti = 900000.0f;
	const float Td = 0.0f;

	static float u =  0.0f;

	//bledy:
	static float e = 0.0f;
	static float e_1 = 0.0f;
	static float e_2 = 0.0f;

	const float r2 = (K*Td)/Tp;
	const float r1 = K*((Tp/(2*Ti))-(2*Td/Tp)-1);
	const float r0 = K*(1+(Tp/(2*Ti))+(Td/Tp));

	//aktualizacja bledow:
	e_2 = e_1;
	e_1 = e;
	e = yzad - y;

	u = r2*e_2 + r1*e_1 + r0*e + u;
	return u;
}

void forward(uint16_t pwm)
{
	  HAL_GPIO_WritePin(IN3_GPIO_Port, IN3_Pin, 1);
	  HAL_GPIO_WritePin(IN4_GPIO_Port, IN4_Pin, 0);
	  HAL_GPIO_WritePin(IN1_GPIO_Port, IN1_Pin, 1);
	  HAL_GPIO_WritePin(IN2_GPIO_Port, IN2_Pin, 0);

	  __HAL_TIM_SET_COMPARE(&htim2, TIM_CHANNEL_2, pwm);
	  __HAL_TIM_SET_COMPARE(&htim2, TIM_CHANNEL_3, pwm);

}

void backward(uint16_t pwm)
{
	  HAL_GPIO_WritePin(IN3_GPIO_Port, IN3_Pin, 0);
	  HAL_GPIO_WritePin(IN4_GPIO_Port, IN4_Pin, 1);
	  HAL_GPIO_WritePin(IN1_GPIO_Port, IN1_Pin, 0);
	  HAL_GPIO_WritePin(IN2_GPIO_Port, IN2_Pin, 1);

	  __HAL_TIM_SET_COMPARE(&htim2, TIM_CHANNEL_2, pwm);
	  __HAL_TIM_SET_COMPARE(&htim2, TIM_CHANNEL_3, pwm);

}

void stop()
{
	  HAL_GPIO_WritePin(IN3_GPIO_Port, IN3_Pin, 0);
	  HAL_GPIO_WritePin(IN4_GPIO_Port, IN4_Pin, 0);
	  HAL_GPIO_WritePin(IN1_GPIO_Port, IN1_Pin, 0);
	  HAL_GPIO_WritePin(IN2_GPIO_Port, IN2_Pin, 0);

	  __HAL_TIM_SET_COMPARE(&htim2, TIM_CHANNEL_2, 0);
	  __HAL_TIM_SET_COMPARE(&htim2, TIM_CHANNEL_3, 0);
}

void HAL_TIM_PeriodElapsedCallback(TIM_HandleTypeDef *htim){
	if(htim->Instance == TIM3){
		const float dt = 0.01f; // pamietaj ze to jest 1/frequency timera
		float accxf, accyf, acczf;
		float gyroxf, gyroyf, gyrozf;
		static float pitch = 0.0f, setPitch = 0.0f, u; // setPitch = -86.6f
		const float max_u = 400.0;
		static uint16_t pwm;

		readAccelerometer(&hi2c1, &accxf, &accyf, &acczf);
		readGyroscope(&hi2c1, &gyroxf, &gyroyf, &gyrozf);
		calculatePitch(&pitch, accxf, accyf, acczf, gyroxf-gyroXoffset, dt);

		u = PID(pitch, setPitch);
		if (u > max_u) u = max_u;
		if (u < -max_u) u = -max_u;
//		printf("Control signal: %3.2f \n", u);

		pwm = (uint16_t)((fabs(u)/max_u)*2000);

		if (u > 5.0)
		{
			forward(pwm);
			printf("Forward with duty cycle: %4d \n", pwm);
		}
		else if (u < -5.0)
		{
			backward(pwm);
			printf("Backward with duty cycle: %4d \n", pwm);
		}
		else
		{
			stop();
			printf("Stop \n");
		}

//		printf("Pitch %3.2f degrees\n",pitch);

		adc_value_servo = (uint16_t)(rx_data[0] << 8) | rx_data[1];
		adc_value_motor = (uint16_t)(rx_data[2] << 8) | rx_data[3];
//		printf("Received servo: %d", adc_value_servo);
//		printf(" Received motor: %d \n", adc_value_motor);

	}
}

void calibrate_gyroscope_offset(float* x_offset, float* y_offset, float* z_offset)
{
    float x, y, z;
    const int samples = 10000;
    float sum_x = 0, sum_y = 0, sum_z = 0;

    for (int i = 0; i < samples; ++i) {
        readGyroscope(&hi2c1, &x, &y, &z);
        sum_x += x;
        sum_y += y;
        sum_z += z;
        HAL_Delay(2);
    }

    *x_offset = sum_x / samples;
    *y_offset = sum_y / samples;
    *z_offset = sum_z / samples;

    printf("Gyro offsets: X=%.3f, Y=%.3f, Z=%.3f", *x_offset, *y_offset, *z_offset);
}
/* USER CODE END 0 */
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

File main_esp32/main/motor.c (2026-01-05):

#include "motor.h"
#include "esp_log.h"
#include "driver/ledc.h"
#include "esp_err.h"
#include <math.h>

static const char *TAG = "motor";

#define LEDC_TIMER              LEDC_TIMER_0
#define LEDC_MODE               LEDC_LOW_SPEED_MODE
#define LEDC_CHANNEL_n1        LEDC_CHANNEL_0
#define LEDC_CHANNEL_n2        LEDC_CHANNEL_1
#define LEDC_CHANNEL_n3        LEDC_CHANNEL_2
#define LEDC_CHANNEL_n4        LEDC_CHANNEL_3
#define LEDC_DUTY_RES           LEDC_TIMER_14_BIT
#define LEDC_MAX_DUTY           16383
#define LEDC_FREQUENCY          500

#define LEDC_OUTPUT_IO_1 33
#define LEDC_OUTPUT_IO_2 25
#define LEDC_OUTPUT_IO_3 26
#define LEDC_OUTPUT_IO_4 27

static float min_pwm_percent = 0.0f;  // Minimum PWM percentage for motor movement
static float motor_threshold_percent = 5.0f;  // Minimum PWM threshold to activate motors

esp_err_t motor_init(void)
{
    ledc_timer_config_t ledc_timer = {
        .speed_mode       = LEDC_MODE,
        .timer_num        = LEDC_TIMER,
        .duty_resolution  = LEDC_DUTY_RES,
        .freq_hz          = LEDC_FREQUENCY,
        .clk_cfg          = LEDC_AUTO_CLK
    };

    esp_err_t err = ledc_timer_config(&ledc_timer);
    if (err != ESP_OK) {
        ESP_LOGE(TAG, "ledc_timer_config failed: %s", esp_err_to_name(err));
        return err;
    }

    ledc_channel_config_t ledc_channel1 = {
        .speed_mode     = LEDC_MODE,
        .channel        = LEDC_CHANNEL_n1,
        .timer_sel      = LEDC_TIMER,
        .intr_type      = LEDC_INTR_DISABLE,
        .gpio_num       = LEDC_OUTPUT_IO_1,
        .duty           = 0,
        .hpoint         = 0
    };
    err = ledc_channel_config(&ledc_channel1);
    if (err != ESP_OK) { ESP_LOGE(TAG, "channel1 config failed: %s", esp_err_to_name(err)); return err; }

    ledc_channel_config_t ledc_channel2 = {
        .speed_mode     = LEDC_MODE,
        .channel        = LEDC_CHANNEL_n2,
        .timer_sel      = LEDC_TIMER,
        .intr_type      = LEDC_INTR_DISABLE,
        .gpio_num       = LEDC_OUTPUT_IO_2,
        .duty           = 0,
        .hpoint         = 0
    };
    err = ledc_channel_config(&ledc_channel2);
    if (err != ESP_OK) { ESP_LOGE(TAG, "channel2 config failed: %s", esp_err_to_name(err)); return err; }

    ledc_channel_config_t ledc_channel_3 = {
        .speed_mode     = LEDC_MODE,
        .channel        = LEDC_CHANNEL_n3,
        .timer_sel      = LEDC_TIMER,
        .intr_type      = LEDC_INTR_DISABLE,
        .gpio_num       = LEDC_OUTPUT_IO_3,
        .duty           = 0,
        .hpoint         = 0
    };
    err = ledc_channel_config(&ledc_channel_3);
    if (err != ESP_OK) { ESP_LOGE(TAG, "channel3 config failed: %s", esp_err_to_name(err)); return err; }

    ledc_channel_config_t ledc_channel4 = {
        .speed_mode     = LEDC_MODE,
        .channel        = LEDC_CHANNEL_n4,
        .timer_sel      = LEDC_TIMER,
        .intr_type      = LEDC_INTR_DISABLE,
        .gpio_num       = LEDC_OUTPUT_IO_4,
        .duty           = 0,
        .hpoint         = 0
    };
    err = ledc_channel_config(&ledc_channel4);
    if (err != ESP_OK) { ESP_LOGE(TAG, "channel4 config failed: %s", esp_err_to_name(err)); return err; }

    ESP_LOGI(TAG, "Motor PWM initialized (SDA=%d SCL=%d @%dHz)", LEDC_OUTPUT_IO_1, LEDC_OUTPUT_IO_2, LEDC_FREQUENCY);
    return ESP_OK;
}

void motor_forward(float pwm_ratio)
{
    uint16_t pwm_duty = (uint16_t)(pwm_ratio * LEDC_MAX_DUTY);
    ledc_set_duty(LEDC_MODE, LEDC_CHANNEL_n1, pwm_duty);
    ledc_update_duty(LEDC_MODE, LEDC_CHANNEL_n1);

    ledc_set_duty(LEDC_MODE, LEDC_CHANNEL_n2, 0);
    ledc_update_duty(LEDC_MODE, LEDC_CHANNEL_n2);

    ledc_set_duty(LEDC_MODE, LEDC_CHANNEL_n3, pwm_duty);
    ledc_update_duty(LEDC_MODE, LEDC_CHANNEL_n3);

    ledc_set_duty(LEDC_MODE, LEDC_CHANNEL_n4, 0);
    ledc_update_duty(LEDC_MODE, LEDC_CHANNEL_n4);
}
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

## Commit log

2025-03-19 Initial commit, created stm32 project
2025-04-04 implemented first working code for controlling wheels, need a larger battery with more power
2025-04-16 Initialised connection with MPU6050 by I2C protocol
    [Self-Balancing Robot Debug.cfg]
2025-04-16 Fixed the WHO_AM_I address to the correct value, small typo error
    [main.c]
2025-04-18 Implemented reading accelerometer values but they seem to change a lot for some reason
2025-04-19 Fixed accelerometer reading, the problem was with int8_t not being uint8_t
    [Self-Balancing Robot.ioc, main.c]
2025-06-03 Created a function to get the accelerometer readings
2025-06-03 Implemented a function to read gyroscpoe values
2025-06-03 Implemented a function to calculate the pitch in the x direction
2025-06-03 Added a hardware timer to regularly update my regulator
2025-06-03 Implemented a not yet tuned PID regulator
2025-07-28 Implemented code to convert control signal u to pwm signal width between 0-2000. Also fixed problem with not correct initialisation in main. For some reason problem with interference from motor-contr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
    [Self-Balancing Robot.ioc, main.c]
2025-07-29 Implemented transmitter for the controller of the robot, for now only with one adc channel
    [Self-Balancing Robot transmitter.cfg, cw6 Debug.cfg]
2025-07-30 Attached a joystick and transmit and receive x and y values
2025-07-31 Implemented algorithm for correct pitch for version with vertically held sensor
    [main.c]
2025-07-31 Implemented function to calculate gyro offsets always at start of the program
2025-07-31 Implemented a version for the esp32, for now just reading from sensor and calculating control signal, no pwm yet
2025-08-01 Esp32, workinggit add . Implemented pid pwm motor control for 1 motor on my esp!
2025-08-04 Established connection via uart and via wifi with pc and used serial studio to display data. Small problem with data freezing when mpu moved. Should try quick plot again
    [esp32_s-b_r.c]
2025-08-05 Implemented displaying the data from the esp in serial studio with the titles, made it less bloking but still having the problem
    [esp32_s-b_r.c]
2025-08-05 Implemented a new way of plotting and communicating with the robot, this time using python socket and matplotlib
2025-08-05 Implemented vertical sliders and text fields to write precise values. Also implemented a folder for the screenshots
    [pid_data_20250805_190540.csv, pid_data_20250805_190944.csv, pid_data_20250805_190953.csv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]
2025-08-05 Implemented csv saving at the closing of the window
    [pid_data_20250805_192018.csv]
2025-08-05 Implemented sending PID values from pc to esp.
    [pid_data_20250805_232646.csv, pid_data_20250805_232914.csv, pid_data_20250805_233004.csv]
2025-08-06 Added a button to send pid values.
2025-08-06 Improved reaction to tilting, and chnaged the wifi connection parameters.
    [pid_data_20250805_190540.csv, pid_data_20250805_190944.csv, pid_data_20250805_190953.csv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]
2025-08-07 Fixed some errors with stm32 code, still freezing because of interference even with improvements.
    [Self-Balancing Robot.ioc, main.c]
2025-08-07 added gpio inputs for the second dc motor
2025-08-08 Improved i2c error management, now error is sent via udp to pc and the reading is tried again.
    [esp32_s-b_r.c]
2025-08-08 Added minimum pwm percentage sending
2025-08-08 Implemented minimal pwm percentage to fix deadband. problem that one side moves quicker then the other as if deadband works only on one side.
    [esp32_s-b_r.c]
2025-08-08 changed format of Ti sending. Problem that after sending, one side tilting creates bigger u values. Before sending no problem, maybe some values aren't updated when sent?
    [esp32_s-b_r.c]
2025-08-08 Fixed the problem with iregular control signal on each side, the problem was with updating and reseting the pid
    [esp32_s-b_r.c]
2025-08-30 I improved the speed of reaction of the robot, I think by decreasing the alpha in the filter.
2025-08-30 Added a sending and receiving of current pid values from the esp to pc, also added a button to request the current pid values.
2025-09-09 Fixed the wifi connection for the new wifi
    [esp32_s-b_r.c]
2025-09-27 added sending of the motor threshold value from the dashboard
2025-10-03 Created a first working version on the esp but using arduinoIDE and some additional libraries. Found problem that you must run cpu at lower frequency, for example 80MHz.
    [self-balancing-robot_arduinoIDE.ino]
2025-10-09 Im trying to create a working version based on arduino code. In progress of transforming dmp.
2025-10-15 Close to completing dmp code with interrupts
2025-10-16 Fixed all necesairy errors and completed a succesful build
    [esp32_s-b_r.c, mpu6050_dmp.c]
2025-10-16 The code runs, but I don't get any interrupts. THe signall seems o stay 0.
2025-10-17 Fixed interrupt not occuring problem, th user control register bit 7 is dmp enable and not bit 6.
    [esp32_s-b_r.c, mpu6050_dmp.c]
2025-10-19 Devideed main task into reader working on interrupts and regulator. Still having some issues.
    [esp32_s-b_r.c]
2025-10-20 Still working on the code, fixed some problems, still getting fifo overflow. Added new copy of code made with help of copilot, which hlped in debugging.
    [mpu6050_dmp.c]
2025-10-20 Fixed the overflow probem! The robot mov, but something isn't right, it is veryslow.
    [esp32_s-b_r.c, mpu6050_dmp.c]
2025-10-20 This is the first time after full code modification that the robot worked just like with arduinoIDE. The wifi migh be the problem.
    [esp32_s-b_r.c]
2025-10-25 Added i2c_com file to refactor code
2025-11-07 Added a new module for the motors, as well as removed unnecesairy motor threshold and min pwm values which were unused, also moved i2c_init to i2c_com module
2025-11-07 Testing connection, still not working however not testedf the changes in main yet
    [esp32_s-b_r.c]
2025-11-08 Removed previous commit additions. Fixed the udp sending error, I pinned the udp sender to a different core and now it works!
    [esp32_s-b_r.c]
2025-11-08 Implemented move buttons sending commands to the esp
2025-11-08 Turning also works. Now I need to fix the withou cable starting and regulator parameters perfectly chosen as well as drive speed and turning offset parameters
    [esp32_s-b_r.c, motor.c]
2025-11-08 New picture of dashboard with buttons
2025-11-13 Implemented new buttons for robot control, fixed errors, implemented turning off pid parameters and sending only when button pressed, added pictures
2025-11-14 Added sending and receiving upright pitch
2025-11-14 Changed so the red highlight is only vissible if the current value is out of bounds, and changed the colors of the values to corolate with the line colors,
2025-11-14 Added buttons connect to robot to send connection requests, then the esp registers such devices and the connection works.
2025-11-14 Implemented a protection for the motors to only start after the pitch values have been stabilised. For some reason for a second or two the right wheel still runs at start.
    [esp32_s-b_r.c]
2025-11-21 Changed the sent values from PID to Kp, 1/Ti and Td to better represent the algorithm, also change the range of values in the app. Current best parameters: Kp:11, 1/TI:0.25, Td:0.05
2025-11-21 Fixed error with inputting text values when connected,added a clear charts button and added a saving and loading of parameters functionality
2025-11-21 Implemented in the app a settings window in the manual tab to send the drive parameters such as drive angle offset. THe values are correctly sent and received by the robot.
    [esp32_s-b_r.c]
2025-12-13 Created my own chassis, ready to print
    [Chassy1.stl]
2025-12-18 Refactored matlab code
    [Chassy1.3mf, Chassy1.stl, Chassy1_cut.stl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]
2025-12-20 Changed code for oppositely attached wheels in new robot chasis
2026-01-05 Fixed issue of a motor starting on startup by changing pins.
    [motor.c]
2026-01-06 Calculated gyro offsets
2026-01-07 Added csv analising program and first csv plots
    [pid_data_share.csv]
2026-01-08 Added min u functionality to fix deadband
    [esp32_s-b_r.c]
2026-01-08 added python csv plotting
    [pid_data_share.csv]
2026-01-09 added ramping of offsets, down back to original value
    [pid_data_share(1).csv, pid_data_share(2).csv, pid_data_share1.csv]
2026-01-16 added control signal error fixing code
    [esp32_s-b_r.c]
2026-01-16 Fix so that r parameters are not calculated every loop cycle.
    [esp32_s-b_r.c]
2026-01-17 Added csv logs
    [pid_data_share(3).csv, pid_data_share(4).csv, pid_data_share(5).csv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]
2026-01-17 Made plots from experiments
    [Kp 12 mu26.csv, Kp 16 mu26.csv, Kp 6 mu26.csv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]
2026-03-14 Update README: ESP32 as primary MCU, esp32_s-b_r_fromArIDE as main firmware
2026-03-27 Restructured project files nd folders
    [Self-Balancing Robot Debug.cfg, Self-Balancing Robot transmitter.cfg, cw6 Debug.cfg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]

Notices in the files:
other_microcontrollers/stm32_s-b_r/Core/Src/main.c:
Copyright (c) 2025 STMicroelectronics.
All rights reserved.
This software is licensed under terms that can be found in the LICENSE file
